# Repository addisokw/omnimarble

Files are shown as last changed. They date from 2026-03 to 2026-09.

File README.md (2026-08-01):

# OmniMarble -- Magnetic Coil Marble Coaster Digital Twin

A physics-accurate digital twin of a magnetic coil-launched marble roller coaster, built on NVIDIA's simulation stack (OpenUSD, PhysX, Kit SDK) with a Physics-Informed Neural Network (PINN) for real-time electromagnetic field computation.

## How It Works

A solenoid coil fires an RLC capacitor discharge through a coil to accelerate a ferromagnetic marble via electromagnetic force. The complete physics chain:

```
RLC Circuit (V, C, L, R)
    |
    v
Current I(t) -- underdamped oscillation with flyback diode
    |
    v
B-field (PINN: 6 inputs -> Br, Bz in single forward pass)
    |
    v
Gradient dB/dr, dB/dz (torch.autograd on PINN output)
    |
    v
Force F = (chi*V/mu0) * (B . nabla)B  -- with saturation + eddy braking
    |
    v
PhysX apply_force_at_pos() -- marble accelerates in Omniverse
```

### The PINN

The analytical Biot-Savart computation (30 loop iterations x scipy elliptic integrals) is replaced by a Physics-Informed Neural Network for real-time inference:

- **Architecture (v8, "physics by construction")**: NVIDIA PhysicsNeMo FullyConnected, 6x256 hidden, SiLU, skip connections. The network outputs a single scalar f; the vector potential is A_phi = r*f and the field is derived inside forward() via autograd: B_r = -r*df/dz, B_z = 2f + r*df/dr. This makes div(B)=0, curl consistency, and the on-axis boundary conditions **exact identities of the architecture**, not trained approximations.
- **Inputs**: (r, z, I, N, R_mean, L) -- spatial position + coil design parameters
- **Outputs**: (A_phi, B_r, B_z) -- same column contract as earlier direct-B models; the shared loader (`scripts/pinn_loader.py`) handles both generations via the checkpoint's `derived_b` flag
- **Key feature**: Model learns B/I (T/A), collapsing dynamic range across the full current range [0.5, 4000] A
- **Training**: 1.42M samples from analytical Biot-Savart (711 configs incl. failure-mined families), losses: data + far-field decay + z-mirror symmetry
- **Validation**: 5-level test suite -- field accuracy, gradient accuracy, force accuracy, design space coverage, physics consistency
- **Force**: needs field gradients, which are second derivatives of f (double backward through the forward-pass graph)

### RLC Circuit

The coil is driven by a capacitor discharge (underdamped RLC):

```
I(t) = (V0 / omega_d * L) * exp(-alpha * t) * sin(omega_d * t)
```

With coupled electromechanical ODE (back-EMF from marble motion), RK4 sub-stepping at 10us resolution, and flyback diode clamping.

Default circuit: 470uF capacitor, 50V charge, L=12.4uH, R_dc=0.080 ohm (config `resistance_ohm`) + 0.01 ESR + 0.02 wiring = R_total~=0.110 ohm -> underdamped (zeta=0.34). Peak current: 327A undamped amplitude V/(omega_d*L); ~198A true damped peak (the two pipelines historically reported different definitions -- see tests/test_coil_physics.py).

### Force Model

Force on a ferromagnetic sphere in a non-uniform field:

```
F = (chi_eff * V / mu0) * (B . nabla)B
```

Where:
- chi_eff = 3.0 (demagnetization-corrected susceptibility for a sphere)
- V = marble volume (mm^3)
- mu0 = 4*pi*1e-4 T*mm/A (mm-scaled)
- B and gradients from PINN autograd

Additional physics:
- **Saturation**: When B_internal > B_sat (1.8T), switches to saturated magnetization model
- **Eddy current braking**: F_eddy proportional to dB/dt and marble conductivity
- **Wire heating**: I^2*R thermal model with copper temperature coefficient

### Units

All computations use mm-based units:
- Distance: mm
- Current: A
- Field: T (Tesla)
- Force: mN (milliNewtons) -- because `[chi * mm^3 / (T*mm/A)] * T * T/mm = A*T*mm = mN`
- Mass: kg (PhysX requirement)
- mu0 = 4*pi*1e-4 T*mm/A

## Quick Start

### Prerequisites

- Python 3.12 or 3.13 — **not 3.14**, which has no `usd-core` wheels. If your
  system Python is newer, pin the project with `uv python pin 3.13` (uv
  downloads a managed interpreter; `.python-version` is gitignored).
- [uv](https://docs.astral.sh/uv/) package manager
- NVIDIA GPU (CUDA) for PINN training and inference
- [NVIDIA Kit SDK](https://github.com/NVIDIA-Omniverse/kit-app-template) for the Omniverse app

### 1. Install Dependencies

```bash
uv sync
```

This installs torch (CUDA 12.8), nvidia-physicsnemo, scipy, matplotlib, numpy, and other dependencies from `pyproject.toml`.

Verify the GPU is actually usable — a Blackwell card (RTX 50-series) needs
`sm_120` in torch's arch list, which the pinned cu128 build provides:

```bash
uv run python -c "import torch; print(torch.__version__, torch.cuda.get_arch_list())"
```

### 2. Train the PINN (or use existing checkpoint)

A trained checkpoint is included at `models/pinn_checkpoint/pinn_best.pt`
(v8 step-250k, `derived_b=True`). To retrain:

```bash
# Generate training data from analytical Biot-Savart (~1.42M samples)
uv run python scripts/generate_training_data.py

# Train v8 PINN (300k steps, ~4.7h on RTX 5090 — the data loss backprops
# through an autograd derivative, so every step is a double backward)
uv run python scripts/train_pinn.py
# Smoke test without touching the production checkpoint:
uv run python scripts/train_pinn.py --steps 500 --batch-size 16384 --out-name pinn_smoke
```

For remote GPU training (e.g., a more powerful machine on your network):
```bash
# Edit REMOTE_HOST and REMOTE_USER in the script, then:
bash scripts/remote_train.sh
# Pulls the result as pinn_v8_candidate.pt + step checkpoints to
# candidates/v8/ — promotion to pinn_best.pt is a manual decision after
# the adoption-gate evaluation (see below).
```

### 3. Validate the PINN

```bash
uv run python scripts/evaluate_pinn.py            # validates pinn_best.pt
uv run python scripts/evaluate_pinn.py --ckpt <path>   # validate a candidate
```

Runs a 5-level validation suite:
1. **Field accuracy**: Bz error vs analytical at 6 currents (12,800 points each)
2. **Gradient accuracy**: dB/dr, dB/dz via autograd vs finite-difference
3. **Force accuracy**: End-to-end F_z comparison at r=0 and r=5mm
4. **Design space**: 64 coil geometries (N x R_mean x L grid)
5. **Physics consistency**: div(B)=0, axial symmetry, z-mirror symmetry

Outputs:
- Console: PASS/FAIL per check
- Plots: `results/plots/pinn_validation/` (5 figures)
- JSON: `results/pinn_validation_report.json`
- Audit: `results/pinn_audit_report.md`

### 4. Analytical B-Field Validation

```bash
uv run python scripts/analytical_bfield.py
```

Generates reference plots in `results/plots/`.

### 5. Coil Design Optimizer

#### Web UI (Gradio)

```bash
uv run python scripts/coil_optimizer_app.py
```

Opens a browser UI for interactive multi-objective coil design optimization.
Features: constraint sliders, target-boost mode, Pareto plot, coupled ODE reranking.

#### CLI

```bash
uv run python scripts/optimize_coil_design.py
```

Headless optimization — prints top designs to console with Pareto plot saved to `results/`.

### 6. Run in NVIDIA Kit (Omniverse)

#### First-time setup

The Kit SDK is not vendored. `omnimarble.kit.bat` expects a
`kit-app-template` checkout **as a sibling of this repo**, with our app and
extension registered inside it. None of that wiring is tracked in git, so it
has to be redone on each new machine.

Verified against kit-app-template **110.2.0**. Windows needs no Visual Studio
— that template disables the C++ build step on `windows-x86_64`.

```cmd
REM 1. Clone kit-app-template next to this project
git clone https://github.com/NVIDIA-Omniverse/kit-app-template.git ..\kit-app-template

REM 2. A fresh clone has no source/ tree at all -- create it.
mkdir ..\kit-app-template\source\apps
mkdir ..\kit-app-template\source\extensions

REM 3. Register the app. Template 110.x expects a FLAT .kit file in
REM    source/apps -- not the nested apps/<name>/<name>.kit of older releases.
copy source\apps\omnimarble\omnimarble.kit ..\kit-app-template\source\apps\

REM 4. Link the extension back here so it stays live-editable. Path.resolve()
REM    follows the junction, so the extension's config/coil_params.json
REM    ancestor-walk still finds this project root.
mklink /J ..\kit-app-template\source\extensions\omni.marble.coaster ^
          source\extensions\omni.marble.coaster
```

Then register the app in the two build files in `../kit-app-template`.
Extensions are auto-discovered from the directory layout, so only the app
needs declaring:

```lua
-- premake5.lua -- append after the "Apps:" comment at the end
define_app("omnimarble.kit")
```

```toml
# repo.toml -- the section already exists with an empty list; fill it in
[repo_precache_exts]
apps = [
    "${root}/source/apps/omnimarble.kit",
]
```

Finally build (downloads ~10GB, one-time):

```cmd
cd ..\kit-app-template
.\repo.bat build
cd ..\omnimarble
```

#### Launch

```cmd
omnimarble.kit.bat
```

This launches Kit with the extension loaded directly from `source/extensions/` (live editing).

**First launch is slow.** The extension pip-installs its own torch into Kit's
embedded Python (3.12) at
`%LOCALAPPDATA%\ov\data\Kit\omnimarble\1.0\pip3-envs\default-3.12` — a
separate environment from this project's `.venv`. Both `torch` and
`torchvision` are pinned to `+cu128` builds in `extension.py`
(`TORCH_CUDA_VERSION` / `TORCHVISION_CUDA_VERSION`); without the pins pip
prefers PyPI's CPU-only Windows wheel and the PINN runs ~13x slower with no
other symptom. A healthy startup logs:

```
[PINN] torch 2.10.0+cu128 (CUDA 12.8), physicsnemo ready
[PINN] Loaded on cuda, checkpoint: ...\pinn_best.pt
```

If it says `CUDA None` or `Loaded on cpu`, a stale wheel is cached:
`omni.kit.pipapi.install` skips whenever the module already imports, so
delete `torch*` from that `pip3-envs` directory and relaunch. Note that
`torchvision` must go back too — `physicsnemo` imports `timm`, which imports
`torchvision`, and its absence surfaces misleadingly as *"Checkpoint was
trained with physicsnemo backend but nvidia-physicsnemo is not installed"*.

#### In the Kit app

1. Click **Load Scene** to open the USD marble coaster scene
2. Click **Configure PhysX** to set CCD, 500Hz timestep, damping
3. Click **Start Simulation** -- marble rolls down the track, triggers IR gates, fires the coil
4. Watch the console log for real-time telemetry (current, field, force, velocity)
5. Adjust **Charge Voltage** and **Capacitance** in the UI panel, click **Update Parameters**
6. Click **Stop Simulation** -- the run's trajectory is written to
   `results/trajectories/kit_launch_<V>V_<C>uF_<timestamp>.csv`

#### Scripted autorun (reproducible launch runs)

The full sequence (load scene, configure PhysX, voltage override, start,
stop after the exit gates fire, write CSV, quit) can be driven without
clicking:

```cmd
omnimarble.kit.bat --/exts/omni.marble.coaster/autorun=true --/exts/omni.marble.coaster/autorunVoltage=300
```

Optional: `autorunMaxSimSeconds` (default 12), `autorunKeepOpen=true` to
leave the app running after the CSV is written.

#### Trajectory export

Every physics step records time, position (world + coil-local z_along/r),
velocities, coil current, capacitor voltage, PINN force and Bz, wire
temperature, and trigger/cutoff flags. The CSV starts with `# key=value`
metadata lines (run parameters, PINN checkpoint + step, gate times,
approach/exit velocity, boost ratio).

A committed reference artifact from the real Kit/PhysX/PINN path:
`results/trajectories/kit_launch_300V_470uF_20260702_174018.csv` — 300V run,
approach 208 mm/s, gate-measured exit 937.5 mm/s (**4.5x boost**).

Use it to check a fresh machine: rerun the autorun command above and diff.
The gate-measured numbers and the `current_A` / `V_cap_V` / `Bz_T` /
`wire_temp_C` columns should match exactly. Positions and velocities drift
slightly (sub-0.1mm, well under 1% on velocity) — that is PhysX solver
nondeterminism across machines, not a broken setup.

#### What happens during simulation

1. Marble rolls down the starter slope under gravity
2. Two velocity-measurement IR gates compute approach velocity
3. Entry gate triggers the RLC discharge
4. Coupled electromechanical ODE computes current with 10us sub-stepping
5. PINN computes B-field, autograd computes gradients, force is applied via PhysX
6. Cutoff gate (MOSFET switch) kills the pulse when marble passes coil center
7. Two exit gates measure the launch velocity and compute boost ratio

## Project Structure

```
config/
  coil_params.json              # Source of truth: coil geometry + RLC circuit params

scripts/
  analytical_bfield.py          # Biot-Savart B-field (elliptic integrals) -- ground truth
  generate_training_data.py     # PINN training data from analytical solution (1.42M samples)
  pinn_loader.py                # Shared checkpoint loader + inference (legacy & derived-B)
  train_pinn.py                 # v8 derived-B PINN training (PhysicsNeMo)
  evaluate_pinn.py              # 5-level PINN validation suite (--ckpt for candidates)
  evaluate_candidates.py        # Multi-checkpoint Pareto comparison
  v7_optimization_diagnostic.py # PINN ranking stability diagnostic (--ckpt)
  physical_accuracy_audit.py    # Physics consistency validation
  validate_physics.py           # Physics validation utilities
  validate_kit_simulation.py    # Headless mirror of Kit physics (--field pinn|analytical)
  coil_optimizer_core.py        # Shared optimization engine (screening + coupled reranking)
  coil_optimizer_app.py         # Gradio web UI for coil design optimizer
  optimize_coil_design.py       # CLI coil design optimizer
  warp_bfield_solver.py         # PINN-based solver for headless simulation
  rlc_circuit.py                # RLC circuit utilities (saturation, eddy braking)
  remote_train.sh               # Remote GPU training via SSH
  generate_coil.py              # Parametric coil mesh generation
  em_force_injection.py         # Standalone EM force simulation
  simulation_loop.py            # Full orchestration loop
  optimize_launch.py            # Differentiable parameter optimization
  create_marble.py              # Marble actor creation
  compose_scene.py              # Scene composition from USD layers
  convert_stl_to_usd.py         # STL → USD conversion
  add_visuals.py                # Visual enhancement
  setup_launch_scene.py         # Launch scene setup
  run_physics_test.py           # Physics test runner

source/                         # NVIDIA Kit extension
  apps/omnimarble/
    omnimarble.kit              # Kit app configuration
  extensions/omni.marble.coaster/
    config/extension.toml       # Extension settings (overridable defaults)
    omni/marble/coaster/
      extension.py              # Main extension: RLC + PINN + PhysX force + UI + autorun
      coil_physics.py           # Pure-Python coil/RLC physics (unit-testable, no Kit deps)

tests/                          # pytest suite (uv run pytest)
  test_coil_physics.py          # Derived values vs config, RLC, gates, cross-checks
  test_rlc_circuit.py           # Saturation/eddy/thermal helpers, mm/mN/T unit system
  test_pinn_loader.py           # Loader version detection, derived-B structural guarantees

models/
  pinn_checkpoint/
    pinn_best.pt                # Production checkpoint: v8 step-250k, derived_b=True
                                # (historical v3-v7 checkpoints live in git history;
                                #  candidates/ holds gitignored periodic checkpoints)

usd/                            # USD scene layers
  marble_coaster_scene.usda     # Composed scene (references all layers)
  marble_actor.usda             # Marble rigid body (mass=0.00408kg)
  coil_geometry.usda            # Coil mesh
  coil_properties.usda          # Coil electrical properties
  track_geometry.usda           # Track collision mesh
  marble_trajectory.usda        # Trajectory reference
  physics_config.usda           # PhysX configuration
  visual_config.usda            # Visual settings

results/
  pinn_validation_report.json   # Validation metrics (machine-readable)
  pinn_audit_report.md          # Full PINN audit trail
  plots/                        # Generated validation plots

omnimarble.kit.bat              # Launch Kit from project root
```

## Configuration

All physical parameters live in `config/coil_params.json`:

```json
{
  "inner_radius_mm": 12.0,
  "outer_radius_mm": 18.0,
  "length_mm": 30.0,
  "num_turns": 30,
  "capacitance_uF": 470.0,
  "charge_voltage_V": 50.0,
  "esr_ohm": 0.01,
  "wiring_resistance_ohm": 0.02,
  "has_flyback_diode": true,
  "switch_type": "MOSFET"
}
```

The Kit extension reads this JSON as the primary source of truth. UI fields in Kit override individual values at runtime.

**Physical-build note:** the persisted `inductance_uH`/`resistance_ohm`
derive from a 12mm-former winding assumption, while the field model (and
the PINN trained on it) places the windings at R_mean = 15mm — no single
physical coil satisfies both. Build real coils to the field geometry and
overwrite these two values with LCR-measured ones; see
`hardware/README.md` ("Supported coils" / build sheet) for the full
analysis.

### Getting a stronger launch

The default 50V/470uF circuit stores only 0.59J — at 50V the EM force barely
changes the trajectory versus a plain gravity roll. For a visible launch:
- **300V / 470uF**: 21J stored — **demonstrated in Kit: 4.5x gate-measured
  boost** (artifact: `results/trajectories/kit_launch_300V_470uF_20260702_174018.csv`)
- To improve efficiency, increase coil inductance (more turns, tighter winding) so the discharge period (~5-20ms) matches the marble's transit time through the coil

## PINN Training Details

### Architecture (v8, physics by construction)
- NVIDIA PhysicsNeMo FullyConnected backbone
- 6 inputs: (r, z, I, N, R_mean, L); 1 raw output: scalar f
- A_phi = r*f; B_r = -r*df/dz and B_z = 2f + r*df/dr derived via autograd
  in forward() — div(B)=0, curl consistency, and on-axis BCs are exact
- 6 hidden layers x 256 units, SiLU activation, skip connections
- B/I normalization: model learns B/I (T/A), caller multiplies by I
- Canonical model + loader: `scripts/pinn_loader.py` (`BFieldPINNDerived`)

### Training data
- 1.42M samples from analytical Biot-Savart
- 75k spatial point pool: 30k dense near coil + 20k boundary-enriched + 5k on-axis + 20k far-field
- 711 parameter configs: grid corners + random + failure-mined N=10/R=8 families
- Per-config: 1500 general + 500 config-adaptive boundary points

### Loss function (v8)
- **Data loss**: MSE on derived B_r/I and B_z/I (backprops through the
  autograd derivative — the dominant per-step cost)
- **Far-field decay** (weight 0.1): fields -> 0 far from coil
- **z-mirror symmetry** (weight 0.5): Bz even, Br odd in z
- Progressive ramp: physics weights scale from 0.1x to 1.0x over first 20k steps
- Removed vs v7 (now exact by construction): curl, divergence-free, on-axis
  boundary conditions; gradient supervision dropped (third-order, marginal)
- Checkpoint selection by data loss + periodic saves for a post-hoc sweep

### Current validation status (v8 step-250k, production — 2026-07-02)

| Level | Check | Result |
|---|---|---|
| 1 | Field accuracy (mean/max Bz error) | FAIL max-only (mean 0.86%, max 27.8% at winding singularities; informational) |
| 2 | Gradient accuracy (dBz/dz mean + P99) | PASS (P99 3.05%) |
| 3 | Force accuracy (peak err, correlation, zero-crossing) | PASS (2.7% / 3.0%, r>0.994) |
| 4 | Design space (64 configs under 5%) | PASS (95.3%, worst 7.75%) |
| 5 | Physics consistency (div=0, symmetry) | PASS (div(B)=0 exact by construction) |

Optimizer-ranking diagnostic vs analytical reference: Spearman r=1.000,
Kendall tau=0.992 over 60 candidates — safe for design optimization.

See `results/pinn_audit_report.md` for the full audit trail including all
training iterations (v1-v8) and the adoption-gate decision.

## License

MIT

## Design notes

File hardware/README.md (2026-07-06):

# OmniMarble driver board (60V-class SELV coilgun pulse driver)

Experimental-side electronics for the OmniMarble digital twin: drives a
real coil with the same fire/cutoff logic as the simulation's Kit
extension and emits telemetry in the sim's trajectory-CSV format for
direct sim-to-real comparison.

> ⚠️ **vNext — on hold (2026-07-06).** This integrated driver board is not the
> current path. The launch concept is still unproven, so we stepped back to a
> bench rig built from off-the-shelf modules — see **[`V0_BENCH_RIG.md`](V0_BENCH_RIG.md)**.
> This board is DRC-clean and preserved; revisit once V0 proves the concept out.

**Status: layout final — fully routed, electrically DRC-clean (0 unconnected /
shorts / clearance / parity), all validators green, and the JLCPCB fab/assembly
package generated (`hardware/fab/jlc/`). Externally reviewed.**

- Operating point: bank charged **24.5–55 V** (63 V-rated capacitors,
  hardware OVP trips 59.1–62.0 V worst-case, asserted in
  `scripts/calcs.py`), one shot per several seconds.
- Bank: 5× snap-in positions, 2200 µF/63 V each (baseline 2 populated =
  4400 µF; max 11000 µF).
- Switch: 3× paralleled 150 V TOLL MOSFETs, designed to a **600 A / 2 ms**
  pulse point; MOSFET-cutoff + freewheel topology reproduces the sim's
  circuit model.
- All engineering numbers in `design-calcs.md` are generated and
  margin-asserted by `scripts/calcs.py` — do not hand-edit.

## Supported coils

The coil is off-board (J5 barrier terminals) and interchangeable. A coil
is **validated** iff it satisfies the envelope swept by `calcs.py` at the
worst configuration (11000 µF bank at 55 V):

> **L ≥ 1 µH AND R_total ≥ 90 mΩ** (total series resistance *including*
> leads and lugs — keep leads short and heavy)

Below the envelope the pulse can exceed the 600 A switch design point —
do not fire. The envelope numbers live in `coil-envelope.json` (generated
by calcs.py) and are printed on the flyback schematic sheet next to J5;
the full safe/unsafe sweep table is in `design-calcs.md`.

### Validated default: demo coil (the coil the simulation models)

| Parameter | Value |
|---|---|
| Turns / wire | 30 × 0.8 mm (AWG20), single layer |
| Geometry | inner r 12 mm, outer r 18 mm, length 30 mm |
| Inductance | 12.406 µH |
| R_dc / R_total | 80.2 mΩ / **110.2 mΩ** (incl. 30 mΩ ESR+wiring budget) |
| At 55 V / 11000 µF | ~420 A peak, ~1.1 ms, 16.6 J |

Using this coil keeps hardware runs directly comparable to Kit runs
(`config/coil_params.json` is the shared source of truth).

### KNOWN MODEL INCONSISTENCY (affects how you build the coil)

The simulation is internally inconsistent about where the windings sit:

- The **field model** (`analytical_bfield.solenoid_field`, which the PINN
  was trained on and the launch force derives from) places all 30 turns
  at a **single 15.0 mm radius** — the mean of config's inner 12 / outer
  18 mm.
- The **circuit model** (Wheeler inductance + winding resistance in
  `coil_physics.py` / `rlc_circuit.py`) assumes a single layer of 0.8 mm
  wire on a 12 mm former (wire centers ~12.4 mm), which is where config's
  persisted `inductance_uH = 12.406` and `resistance_ohm = 0.0802` come
  from.

No physical coil satisfies both. **Resolution: build to the FIELD
geometry** (that is what the PINN/force model is being validated
against), then reconcile the circuit side by measurement — the config
accepts measured `inductance_uH` / `resistance_ohm` and the RLC model
uses whatever is there. Building at 12 mm instead would bias the field
test: closer windings give a measurably stronger on-axis field than the
model predicts.

### Coil build sheet — experiment #1 (demo coil, field-geometry build)

The field model uses **ideal loop centers**: 30 loops at radius 15.0 mm
with centers at `np.linspace(-15, +15, 30)`. The physical winding must
match **turn centers**, not wire edges. Machine-readable spec:
`hardware/scripts/parts.py DEMO_COIL_BUILD`, contract-tested against the
field model by `tests/test_coil_physics.py::
test_demo_coil_build_matches_field_model` (fails if either side drifts).

| Item | Spec |
|---|---|
| Target geometry | **Wire CENTER radius = 15.0 mm** (this is the spec; former OD follows from your wire) |
| Former | For 0.87 mm finished wire OD (0.8 mm copper + 2×0.035 mm enamel): **~29.13 mm OD**. Measure your wire's finished OD and set former OD = 2×(15.0 − OD/2). 32 mm winding window between flanges |
| Wire | 0.8 mm copper (AWG20) enameled magnet wire, ~3 m incl. leads |
| Turns | **30 turns, single layer, one direction** |
| Spacing | **30 turn CENTERS evenly spanning 30.0 mm** → center-to-center pitch **30/29 ≈ 1.034 mm** (not 1.000). First and last turn centers sit at ±15.0 mm from coil center. NOT close-wound (that compresses the span to ~26 mm and shifts the field profile) |
| Leads | Short and heavy (>=AWG16 or doubled), crimped ring lugs to J5 |

Winding tips: score/print **1.034 mm-pitch** guide grooves (or a printed
thread) so the groove *centers* span exactly 30.0 mm; secure the ends
(CA glue) before the winding relaxes; leave 100 mm tails.

**Verify after winding** (LCR meter ~1 kHz + milliohm measurement), then
**write the measured values into `config/coil_params.json`** so sim and
hardware run identical circuit numbers:

| Quantity | Expected (field-geometry build) | Config's current value |
|---|---|---|
| Inductance | **~17.3 uH** (Wheeler at 15 mm) | 12.406 uH (12.4 mm assumption) |
| R_dc | **~97 mOhm** (2.83 m of AWG20) | 80.2 mOhm |
| R_total w/ leads | ~125–130 mOhm | 110.2 mOhm |
| Envelope check | 127 mOhm >= 90 mOhm, 17 uH >= 1 uH — inside; worst-case pulse ~430 A vs the 600 A design point | — |

### Experiment #2 (after #1 validates the model)

Wind the optimizer-recommended coil below; its predicted **+1.0 m/s
boost is itself a falsifiable prediction** of the digital twin.

### Optimizer-recommended coil for THIS board (55 V / 600 A constrained)

`uv run python scripts/optimize_coil_design.py --max-voltage 55 --max-current 600`
(PINN + coupled-ODE screening, 2000 LHS candidates, run 2026-07-03):

| Parameter | Value |
|---|---|
| Turns / wire | **75 × AWG18 (1.024 mm), 3 layers** |
| Geometry | inner r 8.5 mm, outer r 11.8 mm, length 30.5 mm |
| Inductance / R | 49.4 µH / R_dc 99 mΩ → R_total ~129 mΩ |
| Drive point | ~51 V, ~3700 µF (2 bank cans ≈ 4400 µF is the closest fit) |
| Pulse | 228 A peak, 1.6 ms, 4.8 J, ΔT ≈ 0.3 °C |
| Predicted boost | **+1.0 m/s (0.5 → 1.5 m/s, ~3×)** |

Envelope check: 129 mΩ ≥ 90 mΩ and 49.4 µH ≥ 1 µH — inside. Note the
earlier optimizer result quoted in the repo (396 V / 247 J design) was
computed for an unconstrained rig and is **not** a recommendation for
this board.

Caveat: these predictions come from the PINN + analytical circuit model.
Validating them against reality is this board's entire purpose — treat
the boost figure as a hypothesis, not a spec.

## Safety summary (details in design-calcs.md)

- Hardware interlock: FIRE = MCU_FIRE AND ARM-keyswitch (74LVC1G08), and
  the gate drivers are only powered through the E-STOP (NC) + keyswitch
  loop. Explicit pulldowns on all fire nets.
- Boost charging is fail-safe inhibited: a dead/absent Pico cannot charge.
- Hardware OVP (CJ431 ±0.5 %) independent of the MCU.
- Permanent 6.8 k bleed (3τ ≈ 224 s) + commanded 200 Ω dump (<5 V in
  5.3 s) + hardwired live-bank LED.
- Relays never break DC under load (sequencing: precharge before close,
  boost-inhibit before open, dump closes onto 0.28 A).

## Order/production gates

- `uv run python hardware/scripts/validate.py` — schematic completeness
  (review mode; warns on ORDER-REVIEW placeholders).
- `uv run python hardware/scripts/validate.py --production` — fab-export
  gate; **fails** while any ORDER-REVIEW placeholder remains. Currently
  clean: the R24 bank-bleed resistor is resolved to UNI-ROYAL
  25121WJ0682T4E / LCSC **C26073** (6.8 k, 1 W, 2512).
- BOMs: `bom/bom.csv` (engineering), `bom/bom_rail_emit.csv` /
  `bom_rail_recv.csv` (gate-rail variants incl. common parts). JLC
  assembly exports (`fab/jlc/bom_jlc.csv`, `cpl_jlc.csv`) are generated by
  `gen_fab.py`.

## Status & next phases

- **Done:** schematic; 4-layer 2 oz PCB layout (routed, electrically
  DRC-clean, datasheet-verified footprints for TOLL-8 / 9.5 mm barrier /
  5930 shunt / HF3FF relay); and the JLCPCB fab/assembly package
  (`hardware/fab/jlc/`, via `gen_fab.py`).
- **Next:** upload to JLC and clear its DFM (see `fab/jlc/ORDER_NOTES.md`);
  Pico firmware (fire/cutoff state machine, gate timestamps, DMA current
  capture, TRAJ_COLUMNS-compatible telemetry) + `compare_sim_real.py`;
  bring-up procedure — first power at 25 V floor, staged to 55 V, and
  **verify OVP trip + boost regulation before installing max bank
  capacitance or firing into the coil** (the 63 V-cap / 59.1–62.0 V OVP
  window is tight).

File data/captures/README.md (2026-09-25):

# Scope captures (Siglent SDS1202X-E via host/scope.py, omnimarble-vbench)

Columns: `t_s, i_A, v_bank_V`. Trigger on the bank edge (CH2 falling),
centred, 7 ms window, boxcar-averaged to ~2800 rows. `i_A` is the J6
shunt current (0.2 mV/A) -- the shunt is in the FET source leg and NEVER
sees the freewheel tail (TWIN_AUDIT S-9); integrals are shunt-visible only.

| file | date | bank | notes |
|---|---|---|---|
| scope_3can_10v_700.csv | 2026-08-29 | 9.65 V | blank |
| scope_3can_49v_{400,700,1500}.csv | 2026-08-29 | 49.15 V | blanks; tau=275 us tail fitted from these + marble dv |
| scope_3can_30v_700.csv | 2026-09-09 | 29.45 V | blank; 30 V injected prediction 69.6 -> measured 73.3 |
| scope_4can_49v_{400,700,1000,1500}.csv | 2026-09-24 | 49.8 V | blanks, 100 ohm charge resistor |
| scope_4can_22ohm_blank_49v_700.csv | 2026-09-24 | 49.77 V | blank after the 22 ohm swap (inert to the pulse) |
| scope_4can_marble_plus9_49v_700.csv | 2026-09-24 | 49.30 V | FIRST marble-shot capture, +9 offset; early slope -4.4% vs blank |
| scope_5can_49v_{400,700,1000,1500}.csv | 2026-09-24 | 49.8 V | blanks, 22 ohm resistor, PSU 1.0 A |
| scope_5can_marble_fwd_kick1_49v_1500.csv | 2026-09-25 | 49.73 V | marble, first forward kick of a sustain run at 0.85 m/s; early slope -2.7% -> ball at x ~ -17.2 mm |

Scoring and injected predictions: `docs/PREDICTION_45CAN.md`.

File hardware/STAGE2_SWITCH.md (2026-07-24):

# V0 Stage-2 Switch — low-side coil driver

The full-energy switch for the [V0 bench rig](V0_BENCH_RIG.md): a **low-side
N-MOSFET with a dedicated gate driver**. Low-side is the whole trick — the FET
source sits at ground, so the gate driver references ground and there's no
bootstrap / high-side complication.

Use this for Stage 1–2. A cheap prebuilt module can stand in for the Stage-0
electronics bring-up, but not the real experiment — see *Prebuilt board?* below.

## Schematic

```
                       V+  ● bank rail (24–45 V, held by C1)
                           │
          bench(+) ────────┤
          24–45 V,         ├───────────┬───────────────┬──────────────┐
          I-limited        │           │               │              │
                         ══╪══ C1     R_bleed         coil L1      (fire path)
                           │ 4700µF   1 kΩ 5 W        hand-wound        │
                           │ 63 V      │               │                │
                           │           │            ┌──┴──┐             │
                           │           │            │ P1  │ ACS758      │  optional
                           │           │            └──┬──┘ VIOUT→ADC   │  current sense
                           │           │               ● DRAIN          │
                           │           │        D1 ────┤                │
                           │           │       TVS     │   ┌────────────┴┐
                           │           │      5KP48A    ├─D─┤ Q1 IRFB4110 │
                           │           │     (D→S)      │   │  100 V FET  │
              Rg 10 Ω      │           │               │   │             │
   ┌──[///]── G ●──────────┼───────────┼───────────────┼─G─┤  gate       │
   │          │            │           │               │   │             │
   │       Rgs 10k         │           │            S ──┼─S─┤  source     │
   │          │            │           │               │   └─────────────┘
 ┌─┴────────┐ │            │           │               │
 │ U1 TC4420│ │            │           │               │
 │  OUT ────┘ │            │           │               │
 │  VDD ◄───── +12 V (gate-driver rail, small wall-wart)
 │  IN  ◄───── FIRE  (Pico GPIO, 3.3 V — TTL input, drives fine)
 │  GND ──┐   │            │           │               │
 └────────┘   │            │           │               │
    GND ●━━━━━┷━━━━━━━━━━━━┷━━━━━━━━━━━┷━━━━━━━━━━━━━━━━┷━━━━●  ★ STAR GROUND (bank −)
              (logic gnd and power gnd meet here — and ONLY here)
```

## Net list (unambiguous — build from this)

| Node | Everything on it |
|---|---|
| **V+** | bench supply (+), C1 (+), R_bleed (a), coil L1 (a) |
| **DRAIN** | coil L1 (b) → *via P1 ACS758* → Q1 **drain**, D1 TVS **cathode** |
| **GATE** | Q1 **gate**, Rg (b), Rgs (a) |
| **DRV_OUT** | U1 TC4420 OUT, Rg (a) |
| **SOURCE / GND_P** | Q1 **source**, Rgs (b), D1 TVS **anode**, C1 (−), R_bleed (b), bench supply (−) → ★star |
| **VDD12** | U1 VDD, C2/C3 (+), 12 V supply (+) |
| **FIRE** | U1 IN, Pico GPIO |
| **GND_L** | U1 GND, C2/C3 (−), 12 V supply (−), Pico GND → ★star |
| **ISENSE** | P1 ACS758 VIOUT → Pico ADC (P1 VCC→5 V, P1 GND→GND_L) |

## BOM

| Ref | Part | Why |
|---|---|---|
| Q1 | **IRFB4110** (100 V/180 A, TO-220, heatsinked) | pulse-rated FET; use IRFP4668 (200 V) if bank > 45 V |
| U1 | **TC4420CPA** gate driver (DIP-8, 6 A, non-inverting) | breadboardable; TTL input works off the 3.3 V Pico |
| Rg | 10 Ω ½ W | limits gate current / controls dV/dt |
| Rgs | 10 kΩ ¼ W | holds Q1 **off** if the driver is unpowered |
| D1 | **5KP48A** TVS (standoff 48 V, clamp ~77 V) | fast field collapse — see clamp note |
| C1 | 2200–4700 µF / 63 V | the energy bank |
| R_bleed | 1 kΩ 5 W across C1 | safety discharge (~5 s τ) |
| C2, C3 | 1 µF + 100 nF at U1 VDD | driver decoupling — keep leads short |
| P1 | ACS758LCB-100U (optional) | logs the pulse current to the Pico ADC |

## The three things that make or break it

1. **Clamp vs FET voltage.** D1 sits across drain-source; when Q1 opens, the coil
   dumps its current through the TVS, clamping V_DS to ~77 V (< the 100 V FET) and
   collapsing the field in **~150 µs** instead of the ~1 ms a plain freewheel diode
   gives. That fast collapse is the anti-suck-back. Rule: **standoff > bank voltage,
   clamp < 90 V**, so with the 100 V FET **keep the bank ≤ 45 V** and use the 5KP48A.
   Want more voltage → IRFP4668 (200 V) and the margin is huge.
   *A/B test:* swap D1 for an **MBR60100 freewheel** (anode→DRAIN, cathode→V+) and
   you'll see the slower collapse + more suck-back — confirms the clamp earns its place.
2. **Star ground.** The pulse loop (C1 → coil → Q1 → back to C1−) carries hundreds of
   amps. Logic ground (Pico, driver) touches it at **one point only** — the bank
   negative — or pulse noise walks straight into your sensor readings.
3. **Gate default-off.** Rgs guarantees Q1 is off before the driver powers up.

## Prebuilt board? Stage-0 only

Worth knowing after surveying the market: no off-the-shelf board gives you **both**
adequate voltage **and** high pulse current at our bank voltage, because the cheap
opto-isolated MOSFET switch modules are single-FET boards with a fixed volt-amp
product:

| Prebuilt variant | Fits our ≤45 V bank? | Pulse current? |
|---|---|---|
| 5–36 V modules (F5305S, ANMBEST) | ✗ under-volted | — |
| **100 V / 9.4 A** isolated switch | ✓ | ✗ current-starved (9.4 A) |
| 80 V / 18 A | ✓ | ✗ weak |
| 40 V / 50 A · 30 V / 161 A | ✗ under-volted | ✓ (but too low V) |

They're also opto-isolated at PWM speeds (~µs turn-off), which smears the precise
cutoff this whole rig depends on. **Verdict:**
- A **100 V / 9.4 A opto-isolated module** (3.3 V/5 V trigger) is a fine, *isolated,
  zero-build* switch for **Stage 0** — dry-firing the logic and confirming Pico
  timing + sensor reads at low energy without exposing the Pico.
- It is **too current-starved and too timing-smeared for Stage 1–2**. The discrete
  switch above is the only thing that delivers both the current headroom and the
  deterministic ~ns cutoff the timing experiment measures.

Also avoid the "IGBT driver boards" in this market — they're **inverter / welder
back-ends** (continuous SPWM controllers, high-voltage bus, no single-shot trigger),
not triggerable pulse switches, and an IGBT is the wrong device below ~250 V anyway
(VCE(sat) floor + turn-off tail current).

## Safe first-light sequence

1. **No bank connected.** Power 12 V + Pico → pulse FIRE → scope confirms GATE swings
   0 ↔ 12 V.
2. **Bank at ~10 V**, current limit ~0.5 A → fire a 200 µs pulse → scope DRAIN: pulls
   to ~0 on, clamps clean on turn-off.
3. **Add coil + ACS758**, repeat at 10 V, capture the current pulse.
4. **Ramp** per the [V0 Stage 0→1→2 protocol](V0_BENCH_RIG.md). Bleeder + shorting
   stick between voltage changes.

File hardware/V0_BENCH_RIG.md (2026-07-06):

# OmniMarble V0 Bench Rig — single-stage coilgun proof-of-concept

> **Current live hardware path (2026-07-06).** A breadboard-level rig wired from
> off-the-shelf modules to answer one question before we commit to a custom PCB.
> The integrated driver board and gate-rail sensor board are **vNext / on hold** —
> DRC-clean and preserved, to be revisited once V0 proves the concept out.
> See `fab/BOARD_OVERVIEW.md` and `fab/RAIL_OVERVIEW.md`.

## Why this exists

The integrated 55 V driver PCB is a lot of cost and time to commit for a concept
that is still **unproven**. Before spinning custom hardware, prove on the bench
that a **timed coil pulse boosts a steel marble the way the PINN predicts**.

The rig answers exactly one thing:

> **Does measured Δv = v_out − v_in match the sim across a voltage/timing sweep —
> and can we hit the firing timing to get it?**

Everything else is reused unchanged: the **Pico**, the **Waveshare sensor
modules**, and the **entire PINN / sim stack** (`scripts/`, `models/`,
`config/coil_params.json`). The only swap is *custom integrated driver* → *three
COTS modules and a hand-wound coil on the bench*, where every node is probeable.

## Architecture

Two paths — the high-current **power path** and the low-voltage **signal/control
path** — sharing only a star ground at the bank negative terminal.

```
 POWER PATH (high current, ≤60 V SELV)
 ┌──────────────┐   ┌───────────┐   ┌──────────────┐   ┌──────────────────────┐
 │ Bench supply │──▶│ Cap bank  │──▶│ N-MOSFET     │──▶│ Coil  (TVS/zener     │
 │ 24–48 V,     │   │ 2.2–4.7mF │   │ trigger      │   │ clamp across it)     │
 │ I-limited    │   │ 63 V      │   │ module       │   │  ▓▓▓ non-mag tube ▓▓▓ │
 └──────────────┘   │ +bleeder  │   └──────▲───────┘   │   ● steel marble →    │
                    └───────────┘          │ gate      └──────────────────────┘
                                           │
 SIGNAL / CONTROL PATH (logic, 3V3/5V)     │
 ┌────────────────┐                        │
 │ Waveshare A    │─5 lines─┐              │
 │ (BEFORE coil)  │         │        ┌─────┴──────┐
 └────────────────┘         ├──GPIO─▶│ Raspberry  │
 ┌────────────────┐         │        │ Pi Pico    │  reads v_in / v_out,
 │ Waveshare B    │─5 lines─┘        │            │  arms timed OFF, fires gate
 │ (AFTER coil)   │                  └────────────┘
 └────────────────┘
```

- **BEFORE** module → entry velocity `v_in` (marble crossing its 5 close sensors →
  Δt) **and** the coil-ON trigger.
- **AFTER** module → exit velocity `v_out`. `Δv = v_out − v_in` is the coil's boost.
- The Pico closes the loop; the FET module just switches; the supply/bank just
  store energy.

## Bill of materials

Spec-level with example parts — pick from what's on hand / in stock; nothing here
is a pinned SKU.

### Launcher (power path)

| Item | Spec | Example / note |
|---|---|---|
| Bench supply | Adjustable **24–48 V**, current-limited, ≥3 A | The current limit charges the bank gently and sets shot energy. A lab supply is ideal for iterating. |
| Cap bank | **2200–4700 µF, 63 V** electrolytic (one or a few) | ~3–6 J at 50 V — a real pulse, still manageable. Start at the low end. |
| Bleeder | **1–5 kΩ, ≥2 W** across the bank | Safety discharge — the bank holds charge. |
| Switch | **High-power N-MOSFET trigger module**, ≥60–100 V, tens of A peak, signal-in + power terminals | Or bare **IRFB4110** (100 V/180 A) + a gate-driver breakout (TC4420 / UCC27517). |
| Turn-off clamp | **TVS or zener** across the coil, clamp above bank V | Forces fast current decay = clean cutoff. **See suck-back note below.** |
| Coil | Hand-wound **18–22 AWG** enamelled magnet wire on a **non-magnetic** tube | Turns/length per the sim (`config/coil_params.json`). Or repurpose a solenoid. |
| Barrel + projectile | Non-magnetic tube (brass/aluminium/plastic) + **steel marble** | The tube is both barrel and sensor mount. |

**Clamp vs freewheel diode (important):** a plain freewheel diode across the coil
lets current keep circulating after the FET opens — slow decay, the field lingers,
and the marble gets *pulled back* (suck-back). A **TVS/zener clamp** at a higher
voltage forces the current down fast, which is what clean OFF timing needs. Your
existing **MBR60100** works as a starting freewheel, but plan to A/B it against a
TVS clamp.

### Sensing + control (signal path)

| Item | Spec | Example / note |
|---|---|---|
| Sensors | **2× Waveshare ITR20001/T** 5-ch reflective tracker module | Onboard LM393 comparators → **digital** outputs. One before, one after the coil. |
| Controller | **Raspberry Pi Pico** (or Pico W) | Reads sensors, computes firing, drives the FET gate. |
| Interconnect | 10 signal lines (5 + 5) + 5 V + GND | Pico has ~26 GPIO — plenty. |

## Wiring

- **Waveshare:** `VCC → +5 V`, `GND → common GND`. Its 5 digital outputs (per
  board) → **10 Pico GPIO** total. Because the modules threshold on-board, they go
  **straight to GPIO** — no external comparator needed.
- **FET module:** signal input ← a Pico GPIO (the fire line); module GND → common
  GND. Coil in series with the FET; bank across the FET + coil; **clamp across the
  coil**.
- **Grounding:** the pulse loop (bank → FET → coil) dumps tens of amps. Keep that
  loop physically short and tie logic ground to it at a **single star point (bank
  negative)** so pulse noise isn't injected into the sensor logic.

## Control / firing

- **ON:** the BEFORE module detects the marble approaching → Pico fires the coil ON.
- **OFF (the interesting part):** no sensor can sit at the coil *center* (the coil's
  there), so the cutoff is **open-loop from `v_in`**: feed `v_in` to the PINN, which
  predicts the **accelerated** transit-to-center — *not* `distance / v_in`, because
  the marble speeds up under the pulse — and the Pico arms the OFF timer accordingly.
  This is the digital twin closing its own loop.
- **Timing budget:** place the BEFORE module so there are a few ms between measuring
  `v_in` and the marble reaching the coil — enough for the Pico to compute and arm
  OFF. Don't butt it against the coil.

## Staged test protocol

Run in order — each stage de-risks the next.

1. **Stage 0 — dry fire (no marble).** Charge the bank low, fire the FET from the
   Pico, and scope the coil current pulse (current probe or a low-value sense
   resistor). Confirm: the FET switches, the clamp behaves, the Pico timing is what
   you commanded, and **both** Waveshare modules read cleanly. *Goal: the
   electronics + timing work before any marble is involved.*
2. **Stage 1 — first boost (marble, low energy).** Insert the marble, low bank
   voltage. Measure `v_in`, `v_out`. Confirm a **measurable Δv > 0** and that OFF
   fires before center (no suck-back deceleration). *Goal: the launcher does
   something, measurably.*
3. **Stage 2 — sim fit (ramp).** Sweep bank voltage and ON/OFF timing; log `v_in`,
   `v_out`, pulse current, and timing each shot. Fit measured **Δv vs the PINN
   prediction** across the sweep. *Goal: does the sim track reality? If yes, the
   integrated driver is a justified investment.*

## Safety

- Stay **≤60 V (SELV)**; charge through the supply's current limit.
- **Bleeder across the bank** — it holds charge. Bleeder + a shorting-stick habit
  before touching anything.
- **Clamp/diode on the coil** — inductive kick on turn-off.
- Keep the pulse loop short; fuse it if you scale energy.
- One shot per several seconds (thermal).

## Relationship to the rest of the project

- **Sim / PINN:** unchanged. The rig emits the same `v_in` / `v_out` observables the
  twin is validated against (`scripts/`, `models/`, `config/coil_params.json`).
- **vNext (on hold, preserved):** the integrated driver PCB
  (`fab/BOARD_OVERVIEW.md`) and gate-rail sensor board (`fab/RAIL_OVERVIEW.md`) —
  both DRC-clean. Revisit once V0 proves the concept.

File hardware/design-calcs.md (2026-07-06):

# Driver board design calculations

GENERATED by hardware/scripts/calcs.py — do not edit numbers by hand.

Coil model: L=12.406uH, R_total=0.1102Ohm (same values the simulation uses).

## Pulse envelope by bank option (at 55V)

| Bank | regime | zeta | I_pk | t_pk | pulse | E | I2t | FET dTj (shared/fault) | pour dT |
|---|---|---|---|---|---|---|-----|---|---|
| 2200uF | underdamped | 0.73 | 327A | 182us | 0.76ms | 3.3J | 30.2 A^2s | 3.2K / 28K | 0.02K |
| 4400uF | overdamped | 1.04 | 372A | 231us | 1.13ms | 6.7J | 60.1 A^2s | 4.3K / 38K | 0.04K |
| 6600uF | overdamped | 1.27 | 395A | 263us | 1.13ms | 10.0J | 86.4 A^2s | 6.1K / 55K | 0.05K |
| 8800uF | overdamped | 1.47 | 410A | 287us | 1.13ms | 13.3J | 107.4 A^2s | 7.6K / 69K | 0.07K |
| 11000uF | overdamped | 1.64 | 420A | 306us | 1.13ms | 16.6J | 123.9 A^2s | 8.8K / 79K | 0.08K |

Baseline population: **4400uF** (2x 2200uF snap-in).

## Margin checks

| Check | Detail | Result |
|---|---|---|
| Worst-case peak within switch design point | I_pk 420A <= 600A design point | PASS |
| Per-FET pulsed current (shared) | 140A/device <= IDM 760A (3x SCILICON SFT040N150C3 (TOLL, 150V, C42395334)) | PASS |
| FET junction rise, shared conduction | dTj 8.8K < 50K | PASS |
| FET junction rise, single-device fault (baseline bank) | dTj 38.4K < 150K at 4400uF (extreme-bank fault case: 79K — info only, requires all FETs functional) | PASS |
| Blocking diode I2t margin | pulse I2t/pkg 31 A^2s, rating 1012 A^2s (>=10x) | PASS |
| Shunt pulse energy | 24.8 mJ per shot (peak 35W for 1.1ms), continuous rating 15.0W | PASS |
| Pulse pour adiabatic heating | dT 0.08K per shot (20mm 2oz x2, R=0.61 mOhm) | PASS |
| ADC full scale vs worst peak | FS 750A >= 1.25 x 420A (LSB 0.18A) | PASS |
| Charge time (largest bank) | 0.67s to 55V at 0.5A (11000uF) | PASS |
| Dump to <5V (largest bank) | 5.3s through 200 Ohm dump | PASS |
| Passive bleed 3-tau (largest bank) | 3tau = 224s through 7k bleed | PASS |
| V_bank divider inside ADC range at OVP | 3.06V at 63V bank (divider 100k/5.10k) | PASS |
| Boost commanded max (PWM=0, fail state) | 55.0V ~= operating ceiling 55V (RT/RB/RJ = 100k/10k/9.1k) | PASS |
| Boost commanded min below converter floor | 18.7V < 24.5V floor (full PWM = converter idles) | PASS |
| OVP trip floor above commanded max | trip_min 59.1V > 55.0V + 1V margin (nominal 60.5V) | PASS |
| OVP trip ceiling below capacitor rating | trip_max 62.0V < 63V rating - 1V | PASS |
| Dump relay closing current within DC contact class | 0.28A resistive at 55V (HF3FF ~10A/28VDC class; opens only after discharge) | PASS |
| Relay coil drive within MMBT3904 | 30mA coil vs 200mA transistor rating | PASS |
| Coil envelope rectangle exists | L >= 1uH AND R_total >= 90 mOhm (all grid points inside are safe) | PASS |
| Demo coil inside validated envelope | demo 12.406uH/110 mOhm vs envelope L>=1uH, R>=90 mOhm | PASS |

## Sense chain

- Shunt 0.2 mOhm x INA240 gain 20 = 4 mV/A
- ADC full scale 750A at 3.0V ref, LSB 0.18A (12-bit)
- V_bank divider 100k/5.10k -> 2.67V at 55V, standing drain 0.52 mA

## Charger / discharge

- Boost floor 24.5V (cannot regulate below 24V input) — usable charge range 24.5-55V
- Charge current 0.5A avg; precharge 47 Ohm across the charge-relay contacts, relay closes only above 20V bank
- Permanent bleed 6.8k (0.44W at 55V); dump 200 Ohm (2x 100R/10W series) via relay

## Boost setpoint / OVP protection ladder

- VBOOST = 2.5 + RT*(2.5/RB - (VSET-2.5)/RJ) with RT/RB/RJ = 100k / 10k / 9.1k
- PWM=0 (fail state) -> 55.0V; PWM=100% -> 18.7V (< 24.5V floor, idle)
- Ladder: operating 55V < OVP 59.1..62.0V (TL431B +/-0.5% + 1% divider) < capacitor rating 63V
- Boost enable is fail-safe INHIBITED (pull-up holds COMP low; MCU must drive BOOST_EN_N low to charge)
- Relay sequencing: charge relay closes only after precharge equalization, opens only with boost inhibited; dump relay switches <=0.6A resistive.

## Coil safety envelope (worst case: full bank at operating ceiling)

A connected coil is validated iff **L >= 1 uH AND R_total >= 90 mOhm** (total series resistance including leads/wiring), swept at 11000uF / 55V against: I_pk <= 600A, FET dTj < 50K, diode I2t 10x, pour dT < 5K, ADC FS >= 1.25*I_pk.

| L \ R_total | 20m | 30m | 50m | 70m | 90m | 110m | 150m | 200m | 300m | 500m |
|---|---|---|---|---|---|---|---|---|---|---|
| 1uH | **2055A** | **1529A** | **1001A** | **741A** | OK | OK | OK | OK | OK | OK |
| 2uH | **1809A** | **1396A** | **949A** | **714A** | OK | OK | OK | OK | OK | OK |
| 3uH | **1653A** | **1305A** | **909A** | **694A** | OK | OK | OK | OK | OK | OK |
| 4uH | **1540A** | **1235A** | **877A** | **676A** | OK | OK | OK | OK | OK | OK |
| 5uH | **1452A** | **1180A** | **851A** | **661A** | OK | OK | OK | OK | OK | OK |
| 6uH | **1380A** | **1133A** | **827A** | **648A** | OK | OK | OK | OK | OK | OK |
| 8uH | **1268A** | **1058A** | **789A** | **625A** | OK | OK | OK | OK | OK | OK |
| 10uH | **1183A** | **999A** | **757A** | **606A** | OK | OK | OK | OK | OK | OK |
| 12.4uH | **1103A** | **942A** | **725A** | OK | OK | OK | OK | OK | OK | OK |
| 16uH | **1011A** | **876A** | **686A** | OK | OK | OK | OK | OK | OK | OK |
| 20uH | **935A** | **818A** | **651A** | OK | OK | OK | OK | OK | OK | OK |
| 30uH | **805A** | **718A** | OK | OK | OK | OK | OK | OK | OK | OK |
| 40uH | **720A** | **650A** | OK | OK | OK | OK | OK | OK | OK | OK |

(unsafe cells show the offending peak current; envelope excludes them by construction)

## Part constants used (verify against datasheets at order time)

- FET: SCILICON SFT040N150C3 (TOLL, 150V, C42395334), 3x parallel, Rds(on,hot) 6.0 mOhm, IDM 760A, Zth(1ms) 0.12 K/W
- Diode: YFW MBR60100DC (TO-263, 100V Schottky, C6069541), Vf 0.84V, IFSM 450A, I2t 1012 A^2s
- Shunt: Yezhan ASR-M-7-0.2F (5930, C469442, Kelvin-routed)

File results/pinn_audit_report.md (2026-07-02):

# PINN B-Field Model Audit Report

Last updated: 2026-07-02

## 1. Executive Summary

The Physics-Informed Neural Network (PINN) replaces the analytical Biot-Savart
B-field computation for a finite solenoid coilgun. It takes spatial position and
coil design parameters as input and produces the magnetic vector potential and
field components in a single forward pass.

**Current status: v8 "physics-by-construction" model (step-250k checkpoint)
deployed as the single production checkpoint `pinn_best.pt`. 4 of 5 levels
pass; Level 5 passes fully for the first time (div(B) = 0 exact by
architecture). The only remaining FAIL is the informational L1 max criterion
(27.8%, improved from v7's 37.2%; concentrated at winding singularities the
smooth network cannot represent). The v7-era dual-baseline strategy is
retired — see Section 12.**

| Check | v3 | v4 (field) | v5 (regressed) | v7 | **v8 (production)** |
|---|----|----|-----|---|---|
| Level 1: Field accuracy | FAIL | **PASS** | FAIL | FAIL (max only) | FAIL (max only, 27.8%) |
| Level 2: Gradient accuracy | FAIL | FAIL | FAIL | **PASS** (P99) | **PASS** (P99=3.05%) |
| Level 3: Force accuracy | FAIL | **PASS** | **PASS** | **PASS** | **PASS** (2.7%/3.0%) |
| Level 4: Design space | FAIL | FAIL (75%) | FAIL (61%) | **PASS (100%)** | **PASS (95.3%)** |
| Level 5: Physics consistency | FAIL (0/3) | FAIL (2/3) | FAIL (2/3) | FAIL (2/3, div=0.014) | **PASS (3/3, div=0 exact)** |

## 2. Problem Statement

The analytical Biot-Savart solenoid field computation requires 30 loop iterations
with scipy elliptic integrals per evaluation point. For real-time force computation
in Omniverse Kit at 500 Hz PhysX stepping, and for design exploration across coil
geometries, a faster surrogate model was needed.

## 3. Model Architecture

- **Backbone**: NVIDIA PhysicsNeMo FullyConnected
- **Hidden layers**: 6 x 256, SiLU activation, skip connections
- **Parameters**: ~331k
- **Inputs**: (r, z, I, N, R_mean, L) -- spatial position + coil design params
- **Outputs**: (A_phi, B_r, B_z)
- **Key feature**: Model learns B/I (T/A), collapsing dynamic range. Checkpoint flag `current_normalized=True`.

## 4. Training Data

### v3/v4 data (1.02M samples)
- **Spatial**: 30k dense + 20k boundary-enriched + 5k on-axis + 20k sparse = 75k pool
- **Configs**: 256 grid corners (N x R_mean x L at 4 currents) + 244 random + 11 default = 511
- **Points per config**: 1500 general + 500 boundary-enriched = 2000

### v5/v6 data (1.02M samples, same count)
- Same spatial pool and configs as v4
- **Added**: mid-grid parameter configs (N=20,40,65 x R=10,17 x L=22,38,52) for L4 coverage
- **Added**: analytical gradient targets (dBz/dz, dBz/dr) via vectorized finite differences
- **Added**: vectorized batch computation (~50x faster data generation)

## 5. Training History

### v1: Current range too narrow
- **Current range**: [0.5, 20] A
- **Result**: 97% error at operational currents (RLC peak ~320A)
- **Root cause**: Extrapolation failure -- model never saw currents above 20A

### v2: Double-normalization bug
- **Current range**: Fixed to [0.5, 4000] A
- **Result**: Still 97% error
- **Root cause**: `output_scale` double-normalization bug. Targets were divided by
  output_scale during preprocessing, then model output was multiplied by output_scale
  again in forward(), squaring the scaling.

### v3: B/I normalization fix (first passing model)
- **Key change**: Model learns B/I (T/A) not B(T). Collapses dynamic range.
- **Training**: 100k steps, batch_size=32768, lr=1e-3 cosine to 1e-6
- **Loss weights**: data=1.0, curl=0.1, div=0.1, BC=0.01
- **Best loss**: 8.28e-09
- **Hardware**: Local GPU
- **Validation result**: ALL 5 LEVELS FAILED (see Section 6.1)

### v4: Improved data + physics losses + symmetry (current best)
- **Data changes**: 1.02M samples, boundary enrichment, grid corners
- **Loss weight changes**: curl 0.1->1.0, div 0.1->1.0, BC 0.01->0.1
- **New losses**: Symmetry (z-mirror + on-axis Br=0, weight=0.5), gradient self-consistency (weight=0.1)
- **Progressive ramp**: Physics weights scale from 0.1x to 1.0x over first 20k steps
- **Training**: 200k steps, batch_size=131072, PDE batch=8192, BC/sym batch=4096
- **Best loss**: 1.70e-08
- **Hardware**: Remote RTX 5090 (32GB VRAM)
- **Validation result**: 3 of 5 levels pass (see Section 6.2)

### v5: Aggressive gradient supervision (REGRESSED)
- **Key change**: Direct gradient supervision from analytical dBz/dz, dBz/dr targets
- **Loss weights**: div 1.0->5.0, sym 0.5->2.0, grad 0.1->1.0 (against analytical targets)
- **Gradient loss**: Every 2nd step (was every 4th, self-consistency only)
- **Training**: 300k steps, batch_size=131072
- **Best loss**: 1.79e-07 (higher than v4 due to gradient loss dominating)
- **Hardware**: Remote RTX 5090
- **Validation result**: REGRESSED -- only 2/5 pass (see Section 6.3)
- **Root cause**: Gradient supervision weight (1.0) too high. Analytical gradient targets
  have extreme values near coil winding singularities (dBz/dr up to 877 T/mm/A). The model
  spent capacity fitting noisy gradient outliers at the expense of field accuracy. L1 mean
  error tripled (0.6% -> 1.6%), L4 coverage dropped (75% -> 61%), div(B) doubled.
- **Lesson**: Gradient supervision must be gentle (low weight + clipped targets) to act as
  a regularizer, not a primary loss.

### v6: Balanced gradient supervision (TRAINING)
- **Changes from v5**: grad weight 1.0->0.05, div 5.0->2.0, sym 2.0->1.0
- **Gradient targets**: Clipped to p0.5/p99.5 to remove singularity outliers
- **Gradient loss**: Every 4th step
- **Training**: 300k steps, batch_size=131072
- **Hardware**: Remote RTX 5090
- **Status**: Training in progress

## 6. Validation Results

### 6.1. v3 Checkpoint (baseline -- all failed)

Validation run: 2026-03-18, step=100000, loss=8.28e-09

#### Level 1: Field Accuracy -- FAIL
Grid: r in [0.1, 60] mm x z in [-80, 80] mm (12,800 points per current)

| Current | Bz mean err | Bz max err | Result |
|---|---|---|---|
| I=1A | 0.53% | 22.15% | FAIL |
| I=10A | 0.53% | 22.20% | FAIL |
| I=100A | 0.53% | 22.75% | FAIL |
| I=500A | 0.56% | 24.94% | FAIL |
| I=1000A | 0.59% | 27.03% | FAIL |
| I=3000A | 0.72% | 26.88% | FAIL |

#### Level 2: Gradient Accuracy -- FAIL

| Component | Mean err | P95 err | Max err |
|---|---|---|---|
| dBr_dr | 0.36% | 0.14% | 100.22% |
| dBr_dz | 0.44% | 0.28% | 99.65% |
| dBz_dr | 0.17% | 0.16% | 109.94% |
| dBz_dz | 0.63% | 0.28% | 100.35% |

#### Level 3: Force Accuracy -- FAIL

| Position | Peak F err | Pearson r | Zero-cross err | Result |
|---|---|---|---|---|
| r=0mm | 4.2% | 0.9987 | 39.78 mm | FAIL |
| r=5mm | 0.2% | 0.9988 | 0.45 mm | PASS |

#### Level 4: Design Space -- FAIL
- Configs with center Bz error < 5%: **62.5%** (need >= 95%)
- Worst center error: **29.55%** (need < 20%)

#### Level 5: Physics Consistency -- FAIL (0/3)

| Check | Value | Threshold | Result |
|---|---|---|---|
| div(B) = 0 | 0.037459 | < 0.01 | FAIL |
| Axial symmetry | 0.019203 | < 0.01 | FAIL |
| z-symmetry | 0.026788 | < 0.02 | FAIL |

---

### 6.2. v4 Checkpoint (current best -- 3/5 pass)

Validation run: 2026-03-18, step=200000, loss=3.04e-08

#### Level 1: Field Accuracy -- PASS

| Current | Bz mean err | Bz max err | Result |
|---|---|---|---|
| I=1A | 0.67% | 19.46% | PASS |
| I=10A | 0.67% | 19.46% | PASS |
| I=100A | 0.66% | 19.45% | PASS |
| I=500A | 0.61% | 19.40% | PASS |
| I=1000A | 0.57% | 19.31% | PASS |
| I=3000A | 0.58% | 18.79% | PASS |

#### Level 2: Gradient Accuracy -- FAIL

| Component | Mean err | P95 err | Max err |
|---|---|---|---|
| dBr_dr | 0.34% | 0.06% | 100.08% |
| dBr_dz | 0.42% | 0.11% | 99.87% |
| dBz_dr | 0.18% | 0.15% | 112.59% |
| dBz_dz | 0.62% | 0.18% | 99.84% |

#### Level 3: Force Accuracy -- PASS

| Position | Peak F err | Pearson r | Zero-cross err | Result |
|---|---|---|---|---|
| r=0mm | 1.9% | 0.9986 | 0.65 mm | PASS |
| r=5mm | 3.2% | 0.9970 | 0.22 mm | PASS |

#### Level 4: Design Space -- FAIL (improved)
- Configs with center Bz error < 5%: **75.0%** (need >= 95%, was 62.5%)
- Worst center error: **13.23%** (need < 20%, was 29.55% -- now passes worst-case)

#### Level 5: Physics Consistency -- FAIL (2/3 pass)

| Check | v3 value | v4 value | Threshold | Result |
|---|---|---|---|---|
| div(B) = 0 | 0.037459 | **0.019185** | < 0.01 | FAIL |
| Axial symmetry | 0.019203 | **0.002932** | < 0.01 | **PASS** |
| z-symmetry | 0.026788 | **0.012165** | < 0.02 | **PASS** |

---

### 6.3. v5 Checkpoint (regressed -- 2/5 pass)

Validation run: 2026-03-18, step=300000, loss=1.79e-07

**Root cause of regression**: Gradient supervision weight (1.0) too aggressive. Model
prioritized fitting noisy analytical gradient targets near singularities over field accuracy.

#### Level 1: Field Accuracy -- FAIL (regressed from v4 PASS)

| Current | Bz mean err | Bz max err | Result |
|---|---|---|---|
| I=1A | 1.62% | 30.62% | FAIL |
| I=10A | 1.62% | 30.59% | FAIL |
| I=100A | 1.64% | 30.39% | FAIL |
| I=500A | 1.75% | 34.01% | FAIL |
| I=1000A | 1.62% | 38.80% | FAIL |
| I=3000A | 2.15% | 32.63% | FAIL |

Mean errors tripled (0.6% -> 1.6%), max errors nearly doubled (19% -> 31-39%).

#### Level 2: Gradient Accuracy -- FAIL (similar to v4)

| Component | Mean err | P95 err | Max err |
|---|---|---|---|
| dBr_dr | 0.36% | 0.15% | 100.21% |
| dBr_dz | 0.45% | 0.33% | 99.42% |
| dBz_dr | 0.18% | 0.18% | 105.47% |
| dBz_dz | 0.65% | 0.30% | 99.56% |

Despite heavy gradient supervision, max errors unchanged (singularities are fundamental).

#### Level 3: Force Accuracy -- PASS

| Position | Peak F err | Pearson r | Zero-cross err | Result |
|---|---|---|---|---|
| r=0mm | 11.6% | 0.9975 | 0.19 mm | PASS |
| r=5mm | 9.4% | 0.9945 | 0.17 mm | PASS |

Peak errors higher than v4 (1.9/3.2% -> 11.6/9.4%) but still within threshold.

#### Level 4: Design Space -- FAIL (regressed)
- Configs with center Bz error < 5%: **60.9%** (was 75.0%)
- Worst center error: **32.87%** (was 13.23%)

#### Level 5: Physics Consistency -- FAIL (2/3 pass, div regressed)

| Check | v4 value | v5 value | Threshold | Result |
|---|---|---|---|---|
| div(B) = 0 | 0.019185 | **0.037530** | < 0.01 | FAIL |
| Axial symmetry | 0.002932 | **0.006640** | < 0.01 | PASS |
| z-symmetry | 0.012165 | **0.013792** | < 0.02 | PASS |

div(B) doubled despite 5x weight increase -- gradient loss competed with div loss.

## 7. Remaining Failure Analysis

### Level 2: Gradient max errors at singularities
The ~100% max gradient errors occur at isolated grid points near the coil winding surface
(r ~ R_mean = 15mm, z ~ +/-L/2 = +/-15mm). The analytical field has a near-discontinuity
from the current sheet model. A smooth PINN cannot reproduce this. P95 errors (< 0.3%)
confirm accuracy everywhere else. Level 3 (force) passing confirms these points don't
affect integrated quantities. The max threshold of 50% may be unreachable.

### Level 4: Design space corner coverage
~25% of the 64 grid configs still exceed 5% center error. These are configs where geometry
is extreme (e.g. N=80 in L=15mm = very tight winding, or N=10 in L=60mm = very sparse).

### Level 5: Divergence-free residual
div(B) = 0.019 (v4) vs 0.01 threshold. Concentrated near coil boundaries where spatial
gradients are steepest. v5 showed that increasing div weight alone doesn't help if it
competes with other losses.

## 8. Known Limitations

1. **Coil winding singularities**: Discrete current loop model creates near-singularities
   at (r=R_mean, z=loop_position). PINN cannot reproduce these.
2. **Extrapolation**: Accuracy degrades outside training bounds (N < 10 or > 80,
   R_mean < 6 or > 20 mm, L < 15 or > 60 mm, I > 4000 A).
3. **Gradient amplification**: Force uses autograd gradients -- field errors amplified.
4. **Linear B-I assumption**: B/I normalization breaks with ferromagnetic saturation.

## 9. Integration

- **Kit Extension**: `omni.marble.coaster` loads the PINN via `torch.load()` with
  `weights_only=False` (needed for PhysicsNeMo custom layers)
- **Dependencies**: torch and nvidia-physicsnemo installed via `omni.kit.pipapi`
  on first launch. Added `nvidia-physicsnemo` to `pyproject.toml` for standalone use.
- **Force path**: `PINNForceComputer` calls `model.forward()` with autograd enabled,
  computes (chi*V/mu0)(B.grad)B, applies via PhysX `apply_force_at_pos`
- **`current_normalized` flag**: Stored as a buffer in the checkpoint. When True,
  model outputs B/I -- all inference code multiplies by I before computing force
- **`warp_bfield_solver.py`**: Fixed to handle `current_normalized` buffer and I-scaling

### v7 ("design-space"): Audit-driven retraining (superseded by v8)
- **Key changes**: Active failure mining (N=10/R=8 families), gentle gradient supervision
  (weight 0.03, clipped targets), data-loss checkpoint selection, periodic saves
- **Data**: 1.42M samples (711 configs including failure-mined families)
- **Loss weights**: curl=1.0, div=1.5, BC=0.1, sym=0.5, grad=0.03
- **Training**: 300k steps, batch_size=131072
- **Best data loss**: 1.39e-08
- **Hardware**: Remote RTX 5090
- **Validation result**: L2+L3+L4 pass, L1 max and L5 div still fail (see Section 6.4)
- **Deployed as**: `pinn_designspace.pt` (2026-03; retired 2026-07 — was
  byte-identical to `pinn_best.pt`, which is now the single production name)

## 10. Checkpoint Comparison and Dual-Baseline Decision (v7 era, retired)

### Checkpoint sweep (v7 training run)

All periodic checkpoints were evaluated to determine whether an intermediate
checkpoint could achieve v7's L4 coverage while preserving lower L1 max error:

| Checkpoint | L1 mean | L1 P99 | L1 max | L4 %<5 | L4 worst | L3 pk err | L5 div |
|---|---|---|---|---|---|---|---|
| step 50k  | 1.25% | 11.02% | 71.0% | 64% | 15.4% | 7.1% | 0.024 |
| step 100k | 0.75% | 6.57% | 58.1% | 78% | 10.4% | 0.3% | 0.019 |
| step 150k | 0.78% | 4.41% | 42.7% | 92% | 5.4% | 4.9% | 0.016 |
| step 200k | 0.51% | 3.83% | 40.3% | 100% | 4.9% | 5.0% | 0.015 |
| step 250k | 0.58% | 3.49% | 38.0% | 98% | 5.4% | 6.1% | 0.014 |
| **final** | **0.50%** | **3.39%** | **37.2%** | **100%** | **4.8%** | **6.0%** | **0.014** |

**Conclusion**: L4 coverage and L1 max trade off monotonically. No intermediate
checkpoint achieves both v4-style L1 max (<20%) and v7-style L4 completeness (100%).
This is a real tradeoff in the learned solution, not a checkpoint-selection issue.

### Dual-baseline deployment decision (RETIRED 2026-07-02)

**Retirement note**: the strategy below never had a working second leg. The
original v4 checkpoint was lost during the v5-v7 iteration cycle, and the
recipe retrain produced L1 max = 47% — worse at pointwise field accuracy
than the design-space model it was meant to back up. `pinn_fieldaccuracy.pt`
and its training scripts were deleted (recoverable from git history), and
v8 (Section 12) improved L1 max to 27.8% anyway, weakening the case for a
separate field baseline. Preserved as written for the historical record:

Two named baselines are maintained:

**`pinn_designspace.pt`** (v7 final) -- primary production model
- Use for: Kit integration, force computation, design exploration
- Passes: L2 (P99=3.7%), L3 (force), L4 (100% design space)
- L1 max error (37%) concentrated in singular-boundary regions; does not prevent
  Level 3 force accuracy from passing
- L5 div(B) = 0.014, close to 0.01 threshold

**`pinn_fieldaccuracy.pt`** (v4, needs retraining) -- conservative field baseline
- Use for: applications requiring strict pointwise field accuracy near boundaries
- Would pass: L1 (max <20%), L3 (force)
- Known gap: L4 at 75% (design space incomplete)
- Note: original v4 checkpoint was overwritten during v5-v7 iteration cycle.
  Retraining with the v4 recipe is required to restore this baseline.

### Audit findings addressed

| Audit finding | Action taken | Result |
|---|---|---|
| Level 2 mis-specified (max at singularities) | Changed to P99 < 10% | **L2 now PASS** (P99=3.7%) |
| Level 4 under-covered by data | Active failure mining of N=10/R=8 families | **L4 100%** (was 75%) |
| Training loss not reliable for selection | Checkpoint selected by data loss, periodic saves | Better proxy + post-hoc sweep |
| Gradient supervision too aggressive (v5) | Weight 0.03 with clipped targets | No regression from v4 baseline |
| Process optimizing for wrong things | Dual-baseline framing, not single pass/fail | Honest tradeoff documented |

### Next experiment

The remaining L5 div(B) gap (0.014 vs 0.01) and the L1 boundary max error are both
candidates for a **physics-by-construction** approach: deriving B_r and B_z from A_phi
via autograd (B_r = -dA/dz, B_z = (1/r)d(rA)/dr) would guarantee div(B)=0 exactly.
This is the recommended next structural improvement, not further loss weight tuning.

**Done — implemented as v8, see Section 12.**

## 11. Training Infrastructure

- **Local machine**: Windows 11 (development, validation), RTX 5060 Ti
- **Remote training**: Windows SSH to RTX 5090 (32GB VRAM) at 10.10.1.187
  (ICMP firewalled — preflight with `ssh <host> "echo ok"`, not ping)
- **Workflow**: `scripts/remote_train.sh` or manual SCP + SSH
- **Data generation**: Vectorized batch computation (~50x faster than per-point loop)
- **v4 training time**: ~15min for 200k steps at batch_size=131072 on RTX 5090
- **v5 training time**: ~22min for 300k steps at batch_size=131072 on RTX 5090
- **v8 training time**: ~4.7h for 300k steps at batch_size=131072 on RTX 5090
  (the data loss backprops through an autograd derivative, so every step is a
  double backward — ~13x the v7 step cost)

## 12. v8: Physics by Construction (2026-07-02, production)

### Architecture change

The network head was reduced to a single scalar f(r, z, I, N, R_mean, L)
with the ansatz **A_phi = r · f**. The field is derived inside forward()
via autograd:

    B_r = -dA/dz         = -r · df/dz
    B_z = (1/r) d(rA)/dr = 2f + r · df/dr

Consequences, exact by architecture (not by training):
- div(B) = 0 (Level 5's div check is now structural)
- curl consistency B = curl(A)
- A_phi(0, z) = 0 and B_r(0, z) = 0 (the r·f parameterization removes the
  1/r axis singularity — no l'Hopital special case needed)

Losses removed as now-redundant: curl, div, on-axis boundary conditions,
and analytical gradient supervision (third-order through the derived field).
Remaining: data MSE on derived (Br/I, Bz/I), far-field decay (0.1),
z-mirror symmetry (0.5), progressive ramp. Checkpoint selection by data
loss with periodic saves, as in v7. Model/loader code:
`scripts/pinn_loader.py` (BFieldPINNDerived; the loader transparently
supports legacy and derived checkpoints via the `derived_b` flag).

Force gradients are now SECOND derivatives of f (double backward). The Kit
per-step cost was offset by merging the previous two PINN calls per physics
step (get_Bz + compute_force) into one graph build.

ONNX export was dropped (autograd inside forward is not traceable; nothing
consumed it).

### v8 training run

- **Data**: regenerated 1.42M samples / 711 configs (v7 failure-mining recipe)
- **Training**: 300k steps, batch 131072, RTX 5090, ~4.7h
- **Best data loss**: 1.57e-08 (at step 250k)

### Checkpoint sweep (v8)

| Checkpoint | L1 mean | L1 p99 | L1 max | L2 p99 | L3 pk / r | L4 %<5 | L4 worst | L5 div |
|---|---|---|---|---|---|---|---|---|
| step 50k  | 8.33% | 61.6% | 82.5% | 4.52% | 94.1% / 0.497 | 4.7% | 83.2% | 0.00000 |
| step 100k | 5.29% | 28.1% | 72.6% | 4.16% | 36.9% / 0.926 | 6.2% | 66.6% | 0.00000 |
| step 150k | 1.95% | 5.9% | 35.0% | 3.47% | 1.6% / 0.997 | 71.9% | 21.9% | 0.00000 |
| step 200k | 1.35% | 4.8% | 29.0% | 3.17% | 1.7% / 0.996 | 87.5% | 9.4% | 0.00000 |
| **step 250k** | **0.86%** | **2.8%** | **27.8%** | **3.05%** | **3.0% / 0.995** | **95.3%** | **7.75%** | **0.00000** |
| final 300k | 0.77% | 2.9% | 28.0% | 3.04% | 4.2% / 0.994 | 92.2% | 9.0% | 0.00000 |

div(B) is identically zero for every checkpoint — structural, as designed.
The v7 L1-max-vs-L4 tradeoff persists (final 300k has better L1 mean but
dips below the 95% L4 gate); **step 250k** is the only checkpoint passing
every gate criterion and was promoted.

### Adoption gate (all criteria met by step-250k)

| Criterion | Required | v8 step-250k | v7 (previous) |
|---|---|---|---|
| L3 force, both radii | peak<15%, r>0.95, zc<2mm | 2.7%/3.0%, 0.998/0.995, <0.4mm | 7.5%/6.0% |
| L4 design space | >=95% under 5%, worst<20% | 95.3%, 7.75% | 100%, 4.8% |
| L1 field | max <= 37.2% (no worse than v7), mean<5% | 27.8%, 0.86% | 37.2%, 0.50% |
| L5 physics | all pass | div=0 exact, axial+z-sym pass | div FAIL (0.0138) |
| Optimizer ranking | Spearman >= 0.99 | **1.000** (Kendall 0.992, max shift +/-1) | 0.9997 |

Promoted 2026-07-02: `models/pinn_checkpoint/pinn_best.pt` = v8 step-250k
(`model_version=8`, `derived_b=True`). v7 remains recoverable from git
history (commit 9a0c15d's parent).

### First Kit/PhysX launch artifact (300V)

Run via the extension's scripted autorun
(`--/exts/omni.marble.coaster/autorun=true --/exts/omni.marble.coaster/autorunVoltage=300`):

- Approach velocity 208 mm/s (vel_in gate pair); coil fired at entry gate
- 300V / 470uF = 21.1J stored, underdamped (zeta=0.339)
- MOSFET pulse cut at the cutoff gate
- **Gate-measured exit velocity 937.5 mm/s -> 4.5x boost** (README's
  predicted ~4.5x at 300V)
- Artifact: `results/trajectories/kit_launch_300V_470uF_20260702_174018.csv`
  (528 steps at 500 Hz, with metadata headers) — the first trajectory from
  the real Kit/PhysX/PINN path; all earlier committed trajectories came
  from the headless numpy integrators.
- Headless cross-check (`validate_kit_simulation.py --field pinn
  --voltage 300`): 4.2x boost — ratios agree within ~7%. Absolute
  velocities differ through the simpler sphere-bounce track collision
  (approach 149 vs 208 mm/s). Note the two pipelines report I_peak
  differently: the extension logs the undamped amplitude V/(omega_d*L)
  (1963A at 300V) while rlc_circuit reports the true damped peak (1187A);
  same circuit, different definitions (cross-checked in
  tests/test_coil_physics.py).

### Remaining known gaps

1. L1 max error (27.8%) at winding singularities — fundamental to the
   current-sheet analytical model vs a smooth network; informational.
2. All validation is against the analytical model; no physical-hardware
   validation exists yet (the sim-to-real loop of the original plan).
3. `coil_physics.py` (Kit) and `rlc_circuit.py` (headless) duplicate RLC
   physics — cross-checked by tests, unification is tracked tech debt.

---

### Validation run: 2026-03-18 22:38:41 (step=300000, loss=2.02e-08, 3/5 pass)

| Check | Result |
|---|---|
| Level 1: Field accuracy | FAIL |
| Level 2: Gradient accuracy | PASS |
| Level 3: Force accuracy | PASS |
| Level 4: Design space | PASS |
| Level 5: Physics consistency | FAIL |

**Level 1: Field Accuracy**

| Current | Bz mean err | Bz max err | Result |
|---|---|---|---|
| I=1A | 0.50% | 37.68% | FAIL |
| I=10A | 0.50% | 37.63% | FAIL |
| I=100A | 0.50% | 37.17% | FAIL |
| I=500A | 0.49% | 35.49% | FAIL |
| I=1000A | 0.49% | 34.26% | FAIL |
| I=3000A | 0.62% | 38.98% | FAIL |

**Level 2: Gradient Accuracy** (I=318A)

| Component | Mean err | P95 err | Max err |
|---|---|---|---|
| dBr_dr | 0.35% | 0.08% | 100.02% |
| dBr_dz | 0.43% | 0.16% | 99.85% |
| dBz_dr | 0.16% | 0.23% | 107.39% |
| dBz_dz | 0.62% | 0.22% | 100.01% |

**Level 3: Force Accuracy**

| Position | Peak F err | Pearson r | Zero-cross err | Result |
|---|---|---|---|---|
| r=0mm | 7.5% | 0.9941 | 0.68 mm | PASS |
| r=5mm | 6.0% | 0.9980 | 0.02 mm | PASS |

**Level 4: Design Space**
- Configs under 5%: 100.0% (need 95%)
- Worst: 4.80% (need <20%)

**Level 5: Physics Consistency**
- div_B: mean_normalized=0.013843 [FAIL]
- axial_symmetry: max_Br_over_Bz=0.003147 [PASS]
- z_symmetry: max_asymmetry=0.005018 [PASS]

---

### Validation run: 2026-03-19 10:43:05 (step=200000, loss=2.64e-08, 2/5 pass)

| Check | Result |
|---|---|
| Level 1: Field accuracy | FAIL |
| Level 2: Gradient accuracy | PASS |
| Level 3: Force accuracy | PASS |
| Level 4: Design space | FAIL |
| Level 5: Physics consistency | FAIL |

**Level 1: Field Accuracy**

| Current | Bz mean err | Bz max err | Result |
|---|---|---|---|
| I=1A | 0.60% | 47.01% | FAIL |
| I=10A | 0.59% | 47.00% | FAIL |
| I=100A | 0.59% | 46.91% | FAIL |
| I=500A | 0.60% | 46.52% | FAIL |
| I=1000A | 0.61% | 46.02% | FAIL |
| I=3000A | 0.70% | 44.19% | FAIL |

**Level 2: Gradient Accuracy** (I=318A)

| Component | Mean err | P95 err | Max err |
|---|---|---|---|
| dBr_dr | 0.35% | 0.08% | 100.03% |
| dBr_dz | 0.43% | 0.18% | 99.95% |
| dBz_dr | 0.16% | 0.27% | 106.22% |
| dBz_dz | 0.62% | 0.24% | 99.91% |

**Level 3: Force Accuracy**

| Position | Peak F err | Pearson r | Zero-cross err | Result |
|---|---|---|---|---|
| r=0mm | 0.0% | 0.9966 | 0.17 mm | PASS |
| r=5mm | 2.2% | 0.9977 | 0.03 mm | PASS |

**Level 4: Design Space**
- Configs under 5%: 90.6% (need 95%)
- Worst: 11.69% (need <20%)

**Level 5: Physics Consistency**
- div_B: mean_normalized=0.021017 [FAIL]
- axial_symmetry: max_Br_over_Bz=0.002915 [PASS]
- z_symmetry: max_asymmetry=0.007274 [PASS]

---

### Validation run: 2026-07-02 12:43:08 (step=300000, loss=2.02e-08, 3/5 pass)

| Check | Result |
|---|---|
| Level 1: Field accuracy | FAIL |
| Level 2: Gradient accuracy | PASS |
| Level 3: Force accuracy | PASS |
| Level 4: Design space | PASS |
| Level 5: Physics consistency | FAIL |

**Level 1: Field Accuracy**

| Current | Bz mean err | Bz max err | Result |
|---|---|---|---|
| I=1A | 0.50% | 37.68% | FAIL |
| I=10A | 0.50% | 37.63% | FAIL |
| I=100A | 0.50% | 37.17% | FAIL |
| I=500A | 0.49% | 35.49% | FAIL |
| I=1000A | 0.49% | 34.26% | FAIL |
| I=3000A | 0.62% | 38.98% | FAIL |

**Level 2: Gradient Accuracy** (I=318A)

| Component | Mean err | P95 err | Max err |
|---|---|---|---|
| dBr_dr | 0.35% | 0.08% | 100.02% |
| dBr_dz | 0.43% | 0.16% | 99.85% |
| dBz_dr | 0.16% | 0.23% | 107.39% |
| dBz_dz | 0.62% | 0.22% | 100.01% |

**Level 3: Force Accuracy**

| Position | Peak F err | Pearson r | Zero-cross err | Result |
|---|---|---|---|---|
| r=0mm | 7.5% | 0.9941 | 0.68 mm | PASS |
| r=5mm | 6.0% | 0.9980 | 0.02 mm | PASS |

**Level 4: Design Space**
- Configs under 5%: 100.0% (need 95%)
- Worst: 4.80% (need <20%)

**Level 5: Physics Consistency**
- div_B: mean_normalized=0.013843 [FAIL]
- axial_symmetry: max_Br_over_Bz=0.003147 [PASS]
- z_symmetry: max_asymmetry=0.005018 [PASS]

---

### Validation run: 2026-07-02 17:32:11 (step=300000, loss=2.80e-08, 3/5 pass)

| Check | Result |
|---|---|
| Level 1: Field accuracy | FAIL |
| Level 2: Gradient accuracy | PASS |
| Level 3: Force accuracy | PASS |
| Level 4: Design space | FAIL |
| Level 5: Physics consistency | PASS |

**Level 1: Field Accuracy**

| Current | Bz mean err | Bz max err | Result |
|---|---|---|---|
| I=1A | 0.82% | 28.30% | FAIL |
| I=10A | 0.82% | 28.28% | FAIL |
| I=100A | 0.77% | 28.04% | FAIL |
| I=500A | 0.61% | 26.90% | FAIL |
| I=1000A | 0.59% | 25.73% | FAIL |
| I=3000A | 1.24% | 29.25% | FAIL |

**Level 2: Gradient Accuracy** (I=318A)

| Component | Mean err | P95 err | Max err |
|---|---|---|---|
| dBr_dr | 0.34% | 0.05% | 100.02% |
| dBr_dz | 0.42% | 0.12% | 99.78% |
| dBz_dr | 0.16% | 0.15% | 109.26% |
| dBz_dz | 0.61% | 0.15% | 100.02% |

**Level 3: Force Accuracy**

| Position | Peak F err | Pearson r | Zero-cross err | Result |
|---|---|---|---|---|
| r=0mm | 0.7% | 0.9981 | 0.19 mm | PASS |
| r=5mm | 4.2% | 0.9943 | 0.33 mm | PASS |

**Level 4: Design Space**
- Configs under 5%: 92.2% (need 95%)
- Worst: 8.99% (need <20%)

**Level 5: Physics Consistency**
- div_B: mean_normalized=0.000000 [PASS]
- axial_symmetry: max_Br_over_Bz=0.002266 [PASS]
- z_symmetry: max_asymmetry=0.012700 [PASS]

---

### Validation run: 2026-07-02 17:33:29 (step=250000, loss=1.57e-08, 4/5 pass)

| Check | Result |
|---|---|
| Level 1: Field accuracy | FAIL |
| Level 2: Gradient accuracy | PASS |
| Level 3: Force accuracy | PASS |
| Level 4: Design space | PASS |
| Level 5: Physics consistency | PASS |

**Level 1: Field Accuracy**

| Current | Bz mean err | Bz max err | Result |
|---|---|---|---|
| I=1A | 0.92% | 28.04% | FAIL |
| I=10A | 0.91% | 28.03% | FAIL |
| I=100A | 0.86% | 27.85% | FAIL |
| I=500A | 0.70% | 26.83% | FAIL |
| I=1000A | 0.71% | 25.61% | FAIL |
| I=3000A | 1.46% | 29.67% | FAIL |

**Level 2: Gradient Accuracy** (I=318A)

| Component | Mean err | P95 err | Max err |
|---|---|---|---|
| dBr_dr | 0.34% | 0.05% | 100.01% |
| dBr_dz | 0.42% | 0.11% | 99.78% |
| dBz_dr | 0.16% | 0.15% | 109.16% |
| dBz_dz | 0.61% | 0.16% | 99.99% |

**Level 3: Force Accuracy**

| Position | Peak F err | Pearson r | Zero-cross err | Result |
|---|---|---|---|---|
| r=0mm | 2.7% | 0.9981 | 0.33 mm | PASS |
| r=5mm | 3.0% | 0.9945 | 0.39 mm | PASS |

**Level 4: Design Space**
- Configs under 5%: 95.3% (need 95%)
- Worst: 7.75% (need <20%)

**Level 5: Physics Consistency**
- div_B: mean_normalized=0.000000 [PASS]
- axial_symmetry: max_Br_over_Bz=0.002320 [PASS]
- z_symmetry: max_asymmetry=0.017698 [PASS]

---

### Validation run: 2026-07-02 17:47:03 (step=250000, loss=1.57e-08, 4/5 pass)

| Check | Result |
|---|---|
| Level 1: Field accuracy | FAIL |
| Level 2: Gradient accuracy | PASS |
| Level 3: Force accuracy | PASS |
| Level 4: Design space | PASS |
| Level 5: Physics consistency | PASS |

**Level 1: Field Accuracy**

| Current | Bz mean err | Bz max err | Result |
|---|---|---|---|
| I=1A | 0.92% | 28.04% | FAIL |
| I=10A | 0.91% | 28.03% | FAIL |
| I=100A | 0.86% | 27.85% | FAIL |
| I=500A | 0.70% | 26.83% | FAIL |
| I=1000A | 0.71% | 25.61% | FAIL |
| I=3000A | 1.46% | 29.67% | FAIL |

**Level 2: Gradient Accuracy** (I=318A)

| Component | Mean err | P95 err | Max err |
|---|---|---|---|
| dBr_dr | 0.34% | 0.05% | 100.01% |
| dBr_dz | 0.42% | 0.11% | 99.78% |
| dBz_dr | 0.16% | 0.15% | 109.16% |
| dBz_dz | 0.61% | 0.16% | 99.99% |

**Level 3: Force Accuracy**

| Position | Peak F err | Pearson r | Zero-cross err | Result |
|---|---|---|---|---|
| r=0mm | 2.7% | 0.9981 | 0.33 mm | PASS |
| r=5mm | 3.0% | 0.9945 | 0.39 mm | PASS |

**Level 4: Design Space**
- Configs under 5%: 95.3% (need 95%)
- Worst: 7.75% (need <20%)

**Level 5: Physics Consistency**
- div_B: mean_normalized=0.000000 [PASS]
- axial_symmetry: max_Br_over_Bz=0.002320 [PASS]
- z_symmetry: max_asymmetry=0.017698 [PASS]

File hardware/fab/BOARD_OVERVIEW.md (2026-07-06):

# OmniMarble Driver PCB — Board Overview (handoff)

> ⚠️ **vNext — on hold (2026-07-06).** The driver board is **not the current
> path**. The launch concept is still unproven, so the project stepped back to a
> bench rig built from off-the-shelf modules — see
> **[`../V0_BENCH_RIG.md`](../V0_BENCH_RIG.md)**. This board is DRC-clean and fully
> preserved; revisit once V0 proves the concept out. The handoff below remains the
> authoritative description of the board *as designed*.

> Authoritative handoff for the driver board *as designed*. Supersedes
> `REVIEW_HANDOFF.md` (which is from the earlier freerouting routing attempt and
> is out of date). Last updated 2026-07-05.

## What it is
A **coilgun-style pulse driver board** — the experimental-hardware side of the
OmniMarble project. It charges a capacitor bank to an elevated SELV voltage
(~55V), then dumps it through a coil via paralleled power MOSFETs, with
closed-loop current sensing and a safety interlock chain. Designed for JLCPCB
assembly; controlled by an external Raspberry Pi Pico (or compatible) via header.

**Repo:** `hardware/omnimarble-driver/omnimarble-driver.kicad_pcb` (KiCad 10 project)

## Key specs
| | |
|---|---|
| Board | 220 × 150 mm, 4-layer; **2oz outer / 1oz inner** copper; ENIG finish |
| Layer stack | F.Cu (signal) / In1 (GND plane) / In2 (GND plane) / B.Cu (signal) |
| Components | 177 footprints, 108 nets |
| Bank voltage | ≤55V SELV (functional isolation) |
| Status | **Fully routed, electrically DRC-clean** (0 unconnected / shorts / clearance / courtyard / parity / annular / hole). Remaining DRC = 16 cosmetic silk warnings. |

## Architecture / subsystems

**Power input & rails**
- 24V barrel jack (J1) → fuse (F1) → reverse-polarity protection (Q90 AOD4185 P-FET) → `+24V`
- Buck U1 (AP63205) → `+5V`; 12V linear U2 (78L12) → `+12V`; `3V3` for logic/ADC

**Boost charger** (charges the cap bank)
- U4 (UC3843B current-mode PWM) + Q91 (AOD66923 N-FET) + L2 → `VBOOST` → cap bank `VBANK`
- Bank sense divider → U3 (MCP6002) buffers `VBANK_SENSE` / `V24_SENSE`; OVP reference U5 (TL431BIDBZR)
  - **OVP authority caveat:** U5's cathode sits on the UC3843 COMP pin and can only clamp it to
    ~2–2.5 V — it *throttles* the boost but cannot reach zero duty (needs COMP < 1.4 V), so the
    analog OVP slows but does not fully stop a runaway in the divider-fault case. The **authoritative
    over-voltage cut is firmware** (`VBANK_SENSE > threshold → BOOST_EN_N`, driving Q1 which saturates
    COMP with full authority). Accepted for the first spin (see `ORDER_NOTES.md` bring-up item 2);
    rev-2 gives the TL431 full authority via a PNP off BST_VREF onto COMP/Q1.

**Cap bank & pulse stage** (the high-current path)
- 5 bulk caps (2 radial + 3 screw-terminal), `VBANK` pours
- Coil switch: **Q10/Q11/Q12 (SFT040N150C3, 150V) in parallel** — drains on `SW_DRAIN`, sources on `SHUNT_HI`
- Gate drivers U7/U8 (UCC27524A) → `QG1-3` / `DRV1-3`; snubbers `SNB1-3`
- Flyback clamp: MBR60100 diodes D9-D12 (`COIL_HI`); coil connects at J5

**Current sense** (Kelvin)
- Shunt RS1 (low-side, between `SHUNT_HI` and GND), tapped via net-ties NT1/NT2 → `ISNS_P` / `ISNS_N`
- U9 (INA240A1) current-sense amp → `IMON` → U10 (ADS7042 12-bit SAR ADC) → SPI to MCU

**Sensor front-end & logic**
- U11/U12 (LM339 quad comparators): IR-sensor thresholds — `CIN1-6`, `GATE1-6`, `SIG1-6`, `VTH_GATE`

**Safety interlock**
- E-stop (`ESTOP_SENSE` / `ESTOP_OK`), arm (`ARM_SENSE`), fire gating: `MCU_FIRE` AND'd through U6 (74LVC1G08) → `FIRE_GATED`
- Charge/dump relays K1/K2 (`RLY_CHARGE` / `RLY_DUMP`), dump resistors; buzzer BZ1 (Q4 driver)

**MCU interface**
- Pico sockets J9/J10; IDC connectors J6/J7/J8; aux/status LEDs

## How the board is generated (fully scripted, reproducible)
1. `hardware/scripts/gen_schematic.py` → schematic + netlist + `.kicad_pro` (DRC rules)
2. `hardware/scripts/placement.py` → placement, net widths/classes, critical-net taxonomy, authored-copper specs
3. `gen_pcb.py preroute` → places parts, pours planes, authors critical copper
   (Kelvin ties, U10 fine-pitch escape, SHUNT_HI B.Cu bus), exports Specctra DSN
4. `dsn_fixup.py` → net classes, name sanitizing, lock critical/pulse copper → DSN uploaded to
   **DeepPCB** (cloud router) for bulk signal routing (diff-pair mode OFF — see gotchas)
5. **`gen_pcb.py import-clean`** → imports routed SES + deterministic finishing
   (`author_shunt_hi_bus`, `deeppcb_repairs`, `local_finish`, `tidy_silk`,
   `fix_thin_annular`, F/B GND flood, `inject_stackup`, fill) → final board

**Regenerate the exact current board:** copy
`hardware/omnimarble-driver/omnimarble-driver-5-rev-39.ses` → `omnimarble-driver.ses`,
then `gen_pcb.py import-clean` (the frozen routed input — the corrected-netlist
DeepPCB re-route with the FET-strip keepout). This reproduces the DRC-clean board
from scratch; `deeppcb_repairs` re-applies the SHUNT_HI bus/Kelvin/pour fixups the
router couldn't be trusted to keep. Run with KiCad 10's bundled Python:
`"C:\Program Files\KiCad\10.0\bin\python.exe"`.

## Design decisions / gotchas (READ before editing)
- **Critical authored copper is locked and intentional** — a router must not touch it:
  the ISNS **Kelvin ties** (RS1→NT1/NT2); the **U10 dogbone escape** (fine-pitch ADS7042,
  0.2mm stubs to open-space vias); the **SHUNT_HI B.Cu bus** (ties the 3 FET sources to the
  shunt — the F.Cu pour fragments and can't be trusted for that current path).
- **ISNS_P/N are 0.15mm traces** (JLC 2oz min trace/space). A scoped rule in `.kicad_dru`
  (`isns_kelvin_pair`) allows the ISNS_P↔ISNS_N pair down to 0.15mm; clearance to every other net
  stays 0.2mm. `min_track_width` is 0.15mm. Single source of truth: `NET_WIDTHS["ISNS_P/N"] = 0.15`
  in `placement.py` (`local_finish` narrows to it, `validate_widths` checks it). **Do NOT claim
  0.1mm / 0.089mm — that is a 1oz spec and invalid on this 2oz board.**
- **⚠️ ISNS is NOT a tight matched pair after the re-route (first-spin limitation).** The router
  put ISNS_P on B.Cu (~57mm, along y≈81.6) and ISNS_N on a different corridor (~102mm, F.Cu detour
  east to x≈156 and back) — they never travel together, so the earlier "sits ~0.17mm apart, matched
  length" description is obsolete. Effect: a differential pickup loop that adds ~5–10 A of transient
  error on the **rising** edge of the pulse (peak/energy unaffected — see `ORDER_NOTES.md` bring-up
  item 5). A clean local re-author isn't possible — the only corridor paralleling ISNS_P is ~0.7mm
  wide (boxed by ISNS_P at x≈88.4 and ARM_SENSE at x≈89.1), so a proper pair needs a routing pass.
  **Rev-2 fix:** author the full ISNS pair (taps→INA240) as *locked critical copper in preroute* so
  the router routes everything else around it (same pattern as the SHUNT_HI bus / Kelvin ties), and
  **drop the now-moot `isns_kelvin_pair` scoped rule** from `.kicad_dru` — it describes the old
  co-routed pair (min same-layer separation is now 0.65 mm at the INA240 pins) and no longer applies.
- **Never enable a differential-pair router on ISNS** — it hard-couples at ~0.02mm
  (unmanufacturable) every time. Route sense pairs as normal matched nets.
- **Reference designators live on the F.Fab layer**, not silkscreen (dense board); LCSC part
  numbers are hidden property fields (still in the data for the BOM). Physical silk keeps only
  outlines + annotations (K=tab, gate G, polarity, board labels).
- **Voltage domains:** `VBANK` / `VBOOST` / `AUX_BANK` are the elevated rails (VBANK/AUX_BANK
  carry 1.0mm creepage clearance). `SHUNT_HI` is high-*current* but low-*voltage* (low-side
  shunt, near GND) — do **not** give it high-voltage clearance.
- **KiCad 10 API traps:** `PCB_VIA.GetWidth()` needs a layer arg (else blocking-assert hang);
  `board.Remove()` / a second `LoadBoard()` corrupt SWIG footprint wrappers (reload fresh).

## Validation (all green)
Run before any fab-package generation:
- `gen_pcb.py` DRC via `kicad-cli pcb drc --schematic-parity` → **0 electrical** (0 unconnected /
  shorts / clearance / parity), 16 cosmetic silk warnings only.
- `validate.py --production` → PASS (all parts placed; R24 = 6.8k 1W 2512, LCSC C26073).
- `validate_widths.py` → PASS (board matches `NET_WIDTHS`).
- `check_netlist.py` → all safety/topology assertions PASS.
- `calcs.py` → all design margins pass.

## Known items / explicit decisions
- **R24 (bank bleed) = 6.8k 1W 2512, LCSC `C26073`** (UNI-ROYAL 25121WJ0682T4E, in stock). The
  original "6.8k 2W" was inconsistent — a 2512 is a ~1W package and every stocked 6.8k 2512 is 1W
  (2W variants are out of stock). Dissipation is 0.44W (55²/6.8k), so 1W gives 2.2× margin. **JLC
  places it — no hand-install.**
- **WAIVER — gate-drive route lengths are unequal.** Measured DRV1/2/3 ≈ 33.2 / 10.1 / 9.0 mm and
  QG1/2/3 ≈ 28.9 / 24.0 / 23.5 mm, so Q10's total gate loop (~62mm) is ~2× Q11/Q12 (~33mm). Accepted
  because each paralleled FET has its **own gate resistor** (R34/R37/R40) that dominates the drive
  impedance, damps ringing, and balances turn-on; and this is a **µs-scale pulse** application, not
  fast PWM, so a small turn-on skew is tolerable. If tighter current-sharing is ever required,
  re-place/re-route to equalize the loops or scope the FET turn-on and adjust gate-R values.

## State & next step
- Committed. Renders: `hardware/fab/renders/driver_{top,bottom}.png`. DRC report: `hardware/fab/drc_driver.json`.
- **JLCPCB fab package generated** — `hardware/fab/jlc/` (`gen_fab.py`): `omnimarble-driver-gerbers.zip`
  (gerbers+drill), `bom_jlc.csv`, `cpl_jlc.csv`, `drc_driver.json`, and `ORDER_NOTES.md`. Scope is
  **SMT + THT assembly** (159 machine-placed incl. 12 THT; 8 hand-installed sockets/fuses/bulk-caps).
  Regenerate with `gen_fab.py`. Next action: upload to JLC and clear its DFM (see ORDER_NOTES).

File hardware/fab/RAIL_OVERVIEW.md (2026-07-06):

# OmniMarble Gate-Rail (sensor board) — Overview

> ⚠️ **vNext — on hold (2026-07-06).** This break-beam rail is **superseded** on the
> current path: V0 uses off-the-shelf **Waveshare ITR20001** reflective modules
> (before/after the coil) straight into the Pico, so no custom sensor board is built
> for V0 — see **[`../V0_BENCH_RIG.md`](../V0_BENCH_RIG.md)**. This board is DRC-clean
> and preserved; revisit if a spread-station rail is wanted after V0.

The **sense side** of the OmniMarble rig: an IR break-beam sensor rail that
detects the steel marble as it passes six stations along the coil track, so the
measured launch can be compared against the PINN simulation. It is the companion
to the driver board and plugs into the driver's J6 / J7 headers.

## What it is
- **224 × 15 mm, 2-layer, 1 oz** copper. Low-current board (~144 mA on +5 V from
  6 IR LEDs at ~24 mA; sub-mA signal lines), so 1 oz is ample — no 2 oz/4-layer
  like the driver. B.Cu is a solid GND pour; 2 vias (one +5 V, one SIG_SPARE→TP1).
- **6 sensor stations** at z = **-60 / -40 / -20 / +5 / +60 / +120 mm** from the
  coil-center fiducial. Exact x-spacing is asserted to 0.01 mm at board generation
  (`gen_rail_pcb.py`), silk-labelled `z=±NN` per station.

## One PCB, two population variants
Both circuits are drawn on the same board; assembly selects which parts are fitted
(each symbol carries a `Variant` field, and a silk `EMIT [ ] RECV [ ]` checkbox
marks the built board):
- **EMIT** — populate **D1–6** (IR333C-A 5 mm IR LEDs, C5130) + **R1–6** (150 Ω
  0603, C22808). Drive: `+5V → 150 Ω → LED → GND`.
- **RECV** — populate **Q1–6** (PT204-6B 3 mm phototransistors, C5133). Collector
  → `SIGx`, emitter → GND (pulled up on the driver).
- **COMMON** — **J1** (IDC-10, C5665). D and Q share each station footprint; only
  one is fitted per build.

A break-beam setup needs at least one EMIT board and one RECV board facing each
other across the track.

## Connection to the driver
`J1` (IDC-10) pinout:
```
1=+5V  2=GND  3..8=SIG1..6  9=SIG_SPARE  10=GND
```
This matches driver **J7 (RAIL-RECV) pin-for-pin** — J7 carries +5 V/GND *and* the
six SIG lines to the front-end. Driver **J6 (RAIL-EMIT)** is **power-only**
(alternating +5 V/GND on all 10 pins); the EMIT rail only uses J1.1/J1.2/J1.10,
and its SIG traces dead-end at the unpopulated Q pads, so J6 works for EMIT.
**Cables are not interchangeable: never plug a RECV board into J6** (its
phototransistor collectors would sit across +5 V/GND — non-damaging but no sense
data). Label the ribbons; the silk EMIT/RECV checkbox helps.

## How it is generated (fully scripted, deterministic, no autorouter)
1. `gen_gate_rail.py` → schematic (`gate-rail.kicad_sch`) + `.kicad_pro`
2. `kicad-cli sch export netlist` → `gate-rail.net`
3. `gen_rail_pcb.py` → board — places footprints (with parity metadata), hand-emits
   every track / via / GND pour, asserts station spacing, fills. Needs only KiCad's
   bundled Python + `pcbnew`.
4. `gen_fab.py rail` → per-variant fab package (below)

## Status
- ERC **0**; DRC `--schematic-parity` **0 parity / 0 electrical / 0 unconnected**
  (20 cosmetic silk warnings — dense station labels, same as any tight rail).
- Fab package (`hardware/fab/rail/`): 2-layer gerbers + drill, gbrjob 1 oz + rev
  `r1`, **two variant assemblies** — `cpl_rail_emit.csv` (D1-6 + R1-6 + J1 = 13)
  and `cpl_rail_recv.csv` (Q1-6 + J1 = 7) — plus `bom_rail_{emit,recv}.csv` and
  `ORDER_NOTES.md`.

## Ordering (JLC turnkey)
- Enable **THT assembly** (mixed board: the resistors are 0603 SMD; the IDC header,
  IR LEDs and phototransistors are through-hole).
- **One** bare-board gerber order; **two** assembly jobs (EMIT and RECV) — the two
  variants populate different parts on the same footprints, so a single CPL can't
  build both. See `hardware/fab/rail/ORDER_NOTES.md`.
</content>

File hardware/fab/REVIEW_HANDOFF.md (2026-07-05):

> ⚠️ **SUPERSEDED (2026-07-05).** This describes the mid-project freerouting
> attempt (13 unconnected). The board is now **fully routed and DRC-clean** via
> DeepPCB + local finish — see **`BOARD_OVERVIEW.md`** for the current handoff.
> Kept only for history.

# OmniMarble Driver PCB — Review Handoff (rev 3: autorouting pivot)

**Repo:** github.com/addisokw/omnimarble
**Board:** `hardware/omnimarble-driver/omnimarble-driver.kicad_pcb`
**Tool:** KiCad 10.0.4 + freerouting v2.2.4 (run on JDK 26)

## What changed since rev 2

We retired the from-scratch PathFinder router for bulk signal routing and pivoted
to **freerouting v2.2.4**. The earlier "freerouting is unusable" verdict was wrong
— its failures were fixable pipeline defects, not board complexity. New
reproducible pipeline: `preroute → dsn_fixup → freerouting → import-ses → DRC`.

**Key mechanism** (`hardware/scripts/dsn_fixup.py`, new): KiCad exports one flat
0.2 mm net class, so we post-process the DSN to (a) inject real per-width net
classes, (b) give pulse/bank nets the 1.0 mm bank-voltage clearance, (c) lock all
critical + pour copper `(type route)→(type fix)` so the router can't rip it.
`max_passes=30` (the 9999 default caused the prior ~700 GB / non-termination).
The same prepared DSN also uploads to DeepPCB unchanged (parallel option).

## Results (kicad-cli, `--schematic-parity`)

| Metric | Scripted (rev 2) | freerouting (now) |
|---|---|---|
| Unconnected | 118 | **13** |
| Clearance | 59 (to 0.010 mm on FIRE_GATED) | **6** (all mild 0.15 mm signal) |
| Shorts / crossings / parity | 0 / 0 / 0 | **0 / 0 / 0** |
| Hole-to-hole / hole-clearance | — | **0 / 0** |

The clearance quality is the material improvement: no more
sub-manufacturing-tolerance near-shorts on safety nets; the 6 remaining are benign
0.15 mm gaps on ADC-SPI / 3V3 / IMON_F.

## The 13 unconnected (honest categorization)

- **3 critical, unrouted by design**: SHUNT_HI Kelvin (×2), BST_G boost gate.
  Deterministic critical-net authoring (plan Step 1) was deferred to validate the
  freerouting pipeline first; these are exactly what that step authors and locks —
  which also satisfies the rev-2 requirement that critical nets be hand-finished,
  not autorouted.
- **5 GND**: congested fine-pitch pads the full-board GND pour + via-in-pad
  stitching couldn't reach.
- **5 signal taps**: 3V3 (U10), +5V, +24V (U2), VBANK_DIV (U3) in dense areas.

## Two decisions needing scrutiny

1. **Design-rule relaxation**: board min-via lowered 0.5→0.4 mm, min-hole
   0.3→0.2 mm (in `.kicad_pro`) to allow the 0.45/0.25 GND via-in-pad stitching.
   JLC-manufacturable, but a real rule change — please confirm acceptable for this
   board class.
2. **New architecture**: full-board F.Cu/B.Cu GND pours added (`build_zones`), so
   GND pads connect to the pour directly rather than each needing a threaded via.
   Standard practice, but it substantially changes the copper — worth confirming no
   unintended coupling into the analog / Kelvin / boost-sense sections.

## Still not fab-ready (unchanged gate from rev 2)

0 unconnected / 0 clearance / 0 parity, **then** manual power-loop / Kelvin / boost
review with net-highlighted screenshots (symmetric FET copper, true Kelvin pickup
at the shunt, intentional thermal reliefs on pulse pads), then silkscreen cleanup +
fab exports. Order-time gates still open: 6.8 k bleed LCSC C-number, relay NO/NC
continuity.

## What I want your opinion on

- Is the freerouted track geometry acceptable for the noncritical nets, given
  critical nets will be separately authored and locked?
- The min-via/hole relaxation and the full-board GND pour — any objection?
- Anything the DRC-clean copper is masking that a highlighted-net review should
  target first?

## Artifacts

- Renders: `hardware/fab/renders/driver_top.png`, `driver_bottom.png`
- Scorecard dashboard: `hardware/fab/driver_pcb_review.html`
- DRC report (regenerate): `kicad-cli pcb drc --schematic-parity --format json
  -o hardware/fab/drc_driver.json hardware/omnimarble-driver/omnimarble-driver.kicad_pcb`
- Pipeline scripts: `hardware/scripts/dsn_fixup.py`, `gen_pcb.py` (modes:
  preroute / import-ses / repair), `placement.py` (CRITICAL_NETS / PLANE_NETS /
  netclass_rules)

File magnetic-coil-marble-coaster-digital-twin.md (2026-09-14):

# Magnetic Coil Marble Roller Coaster — Digital Twin Implementation Plan

## Project overview

Build a digital twin of a magnetic coil-launched marble roller coaster using NVIDIA's simulation stack. The system simulates electromagnetic coil launchers accelerating a steel marble along a 3D-printed track, with the goal of predicting physical behavior digitally before building, and eventually running a live sim-to-real feedback loop.

### What we have

- **One STL file** of the roller coaster track (triangle mesh, no semantic separation, no physics)
- **No CAD model of the coil** — we need to generate a parametric solenoid geometry programmatically
- **Target marble**: ~10mm diameter steel ball bearing (density ~7800 kg/m³)
- **Target coil**: single-stage solenoid launcher (copper wire, ~20-40 turns, ~12-24V pulse)

### What we're building

1. **STL → OpenUSD pipeline** — convert the track mesh into a physics-ready USD scene
2. **Parametric coil generator** — programmatically create solenoid geometry in USD
3. **PhysicsNeMo PINN electromagnetic surrogate** — train a neural network on Maxwell's magnetostatic equations to predict B-field for any coil configuration in real-time
4. **PhysX rigid body simulation** — marble dynamics on the track with gravity, friction, contact
5. **Warp integration** — GPU-accelerated marble + EM force coupling, differentiable for optimization
6. **Omniverse scene** — composed USD layers for visualization and sim

---

## Phase 1: STL to OpenUSD conversion

### 1.1 Mesh preparation

The STL is raw triangle soup. Before converting, we need to clean and optionally split it.

**Dependencies**: `trimesh`, `numpy`, `pxr` (OpenUSD Python bindings)

```bash
pip install trimesh numpy --break-system-packages
```

For the `pxr` USD bindings, install via:
```bash
pip install usd-core --break-system-packages
```

**Steps**:

1. Load the STL with trimesh
2. Fix normals (ensure consistent winding)
3. Remove degenerate triangles (zero-area faces)
4. Optionally decimate if triangle count > 100k (for PhysX performance)
5. Identify and separate disconnected components (track sections, supports, etc.) using `trimesh.graph.connected_components`
6. Export each component as a separate mesh in the USD scene

```python
import trimesh
import numpy as np

mesh = trimesh.load("track.stl")
mesh.fix_normals()
mesh.remove_degenerate_faces()
mesh.remove_duplicate_faces()

# Split into connected components
components = mesh.split(only_watertight=False)
print(f"Found {len(components)} connected components")

# Identify the main track (largest component by face count)
track_mesh = max(components, key=lambda m: len(m.faces))
support_meshes = [m for m in components if m is not track_mesh]
```

### 1.2 Write to OpenUSD

Create a USD stage with proper units, up-axis, and the track mesh as a `UsdGeom.Mesh`.

**Critical**: STL files have no unit metadata. You must know what units your CAD software used. If the STL is in millimeters, set `metersPerUnit = 0.001`.

```python
from pxr import Usd, UsdGeom, UsdPhysics, Gf, Vt, Sdf

stage = Usd.Stage.CreateNew("marble_coaster.usda")

# Set scene metadata — CRITICAL: match your STL's units
UsdGeom.SetStageMetersPerUnit(stage, 0.001)  # if STL is in mm
UsdGeom.SetStageUpAxis(stage, UsdGeom.Tokens.z)  # match your CAD

# Create world root
world = UsdGeom.Xform.Define(stage, "/World")

# Create the track mesh
track_prim = UsdGeom.Mesh.Define(stage, "/World/Track")
track_prim.CreatePointsAttr(Vt.Vec3fArray([Gf.Vec3f(*v) for v in track_mesh.vertices]))
track_prim.CreateFaceVertexCountsAttr(Vt.IntArray([3] * len(track_mesh.faces)))
track_prim.CreateFaceVertexIndicesAttr(Vt.IntArray(track_mesh.faces.flatten().tolist()))
track_prim.CreateSubdivisionSchemeAttr("none")  # keep triangles as-is

# Compute and set normals
normals = track_mesh.vertex_normals
track_prim.CreateNormalsAttr(Vt.Vec3fArray([Gf.Vec3f(*n) for n in normals]))
track_prim.SetNormalsInterpolation("vertex")

# Set extent (bounding box)
bounds = track_mesh.bounds
track_prim.CreateExtentAttr(Vt.Vec3fArray([
    Gf.Vec3f(*bounds[0]), Gf.Vec3f(*bounds[1])
]))

stage.GetRootLayer().Save()
```

### 1.3 Apply physics schemas to the track

The track is a **static collider** — it doesn't move, but the marble collides with it.

```python
# Make the track a static collider using exact triangle mesh
track_p = stage.GetPrimAtPath("/World/Track")
UsdPhysics.CollisionAPI.Apply(track_p)
mesh_collision = UsdPhysics.MeshCollisionAPI.Apply(track_p)
mesh_collision.GetApproximationAttr().Set("none")  # exact triangle mesh, no simplification

# Create a physics scene
physics_scene = UsdPhysics.Scene.Define(stage, "/World/PhysicsScene")
physics_scene.CreateGravityDirectionAttr(Gf.Vec3f(0, 0, -1))
physics_scene.CreateGravityMagnitudeAttr(9810.0)  # mm/s² if stage is in mm
```

### 1.4 Create the marble

The marble is a **dynamic rigid body** with a sphere collider.

```python
# Marble transform
marble_xform = UsdGeom.Xform.Define(stage, "/World/Marble")
marble_xform.AddTranslateOp().Set(Gf.Vec3d(0, 0, 50))  # starting position (adjust)

# Marble visual geometry
marble_geom = UsdGeom.Sphere.Define(stage, "/World/Marble/Geom")
marble_geom.CreateRadiusAttr(5.0)  # 5mm radius = 10mm diameter marble

# Rigid body API on the Xform (parent)
rb = UsdPhysics.RigidBodyAPI.Apply(marble_xform.GetPrim())

# Collision API on the sphere geometry
UsdPhysics.CollisionAPI.Apply(marble_geom.GetPrim())

# Mass properties
mass_api = UsdPhysics.MassAPI.Apply(marble_xform.GetPrim())
mass_api.CreateDensityAttr(7.8e-3)  # steel density in g/mm³ (7800 kg/m³)
```

### 1.5 Physics materials

```python
# Track material (PLA/resin surface)
track_mat_path = "/World/Materials/TrackMaterial"
track_mat_prim = stage.DefinePrim(track_mat_path)
track_phys_mat = UsdPhysics.MaterialAPI.Apply(track_mat_prim)
track_phys_mat.CreateStaticFrictionAttr(0.4)
track_phys_mat.CreateDynamicFrictionAttr(0.3)
track_phys_mat.CreateRestitutionAttr(0.3)  # low bounce on track

# Marble material (steel)
marble_mat_path = "/World/Materials/MarbleMaterial"
marble_mat_prim = stage.DefinePrim(marble_mat_path)
marble_phys_mat = UsdPhysics.MaterialAPI.Apply(marble_mat_prim)
marble_phys_mat.CreateStaticFrictionAttr(0.5)
marble_phys_mat.CreateDynamicFrictionAttr(0.35)
marble_phys_mat.CreateRestitutionAttr(0.6)  # steel bounces moderately

# Bind materials (using UsdShade binding)
from pxr import UsdShade
UsdShade.MaterialBindingAPI.Apply(stage.GetPrimAtPath("/World/Track")).Bind(
    UsdShade.Material(track_mat_prim))
UsdShade.MaterialBindingAPI.Apply(stage.GetPrimAtPath("/World/Marble/Geom")).Bind(
    UsdShade.Material(marble_mat_prim))
```

### 1.6 PhysX simulation tuning for the marble

```python
from pxr import PhysxSchema

# Enable CCD on the marble (critical — small fast object after launch)
physx_rb = PhysxSchema.PhysxRigidBodyAPI.Apply(marble_xform.GetPrim())
physx_rb.CreateEnableCCDAttr(True)

# Increase contact offset slightly for better contact detection on curved track
physx_col = PhysxSchema.PhysxCollisionAPI.Apply(marble_geom.GetPrim())
physx_col.CreateContactOffsetAttr(2.0)  # 2mm contact offset
physx_col.CreateRestOffsetAttr(0.0)

# Configure the physics scene for accurate marble simulation
physx_scene = PhysxSchema.PhysxSceneAPI.Apply(physics_scene.GetPrim())
physx_scene.CreateTimeStepsPerSecondAttr(120)  # 120 Hz minimum for small marble
physx_scene.CreateEnableCCDAttr(True)
# TGS solver is the default in PhysX 5.x — no explicit setting needed
# It applies friction every iteration, which gives smooth rolling behavior

stage.GetRootLayer().Save()
```

---

## Phase 2: Parametric coil generator

Since we don't have a coil CAD model, we generate one programmatically. The coil is a solenoid — a helical winding of wire around a cylindrical bore.

### 2.1 Coil geometry parameters

```python
# Coil parameters (adjust to your physical build)
COIL_PARAMS = {
    "inner_radius": 8.0,      # mm — must be > marble radius (5mm) + clearance
    "outer_radius": 14.0,     # mm — wire winding thickness
    "length": 30.0,           # mm — coil length along axis
    "num_turns": 30,          # number of wire turns
    "wire_diameter": 0.8,     # mm — wire gauge (AWG 20 ≈ 0.8mm)
    "coil_position": [0, 0, 20],  # mm — center position on track
    "coil_axis": [1, 0, 0],   # direction the marble travels through
}
```

### 2.2 Generate coil mesh

Create a simplified cylindrical shell representation (not individual wire turns — that's for the EM solver, not the visual/collision mesh).

```python
def create_coil_mesh(stage, path, params):
    """Create a cylindrical coil housing as a USD mesh."""
    import math

    r_inner = params["inner_radius"]
    r_outer = params["outer_radius"]
    length = params["length"]
    n_segments = 32  # circumferential resolution

    # Generate vertices for inner and outer cylinders, top and bottom caps
    verts = []
    faces = []
    counts = []

    for i in range(n_segments):
        angle = 2 * math.pi * i / n_segments
        cos_a, sin_a = math.cos(angle), math.sin(angle)

        # 4 rings: inner-bottom, inner-top, outer-bottom, outer-top
        verts.append(Gf.Vec3f(0, r_inner * cos_a, r_inner * sin_a))           # 0: inner bottom
        verts.append(Gf.Vec3f(length, r_inner * cos_a, r_inner * sin_a))      # 1: inner top
        verts.append(Gf.Vec3f(0, r_outer * cos_a, r_outer * sin_a))           # 2: outer bottom
        verts.append(Gf.Vec3f(length, r_outer * cos_a, r_outer * sin_a))      # 3: outer top

    # Generate quad faces connecting adjacent segments
    for i in range(n_segments):
        j = (i + 1) % n_segments
        base_i = i * 4
        base_j = j * 4

        # Outer wall
        faces.extend([base_i + 2, base_j + 2, base_j + 3, base_i + 3])
        counts.append(4)
        # Inner wall
        faces.extend([base_i + 0, base_i + 1, base_j + 1, base_j + 0])
        counts.append(4)
        # Bottom cap
        faces.extend([base_i + 0, base_j + 0, base_j + 2, base_i + 2])
        counts.append(4)
        # Top cap
        faces.extend([base_i + 1, base_i + 3, base_j + 3, base_j + 1])
        counts.append(4)

    coil_mesh = UsdGeom.Mesh.Define(stage, path)
    coil_mesh.CreatePointsAttr(Vt.Vec3fArray(verts))
    coil_mesh.CreateFaceVertexCountsAttr(Vt.IntArray(counts))
    coil_mesh.CreateFaceVertexIndicesAttr(Vt.IntArray(faces))
    coil_mesh.CreateSubdivisionSchemeAttr("none")

    # Position the coil
    xform = UsdGeom.Xformable(coil_mesh.GetPrim())
    xform.AddTranslateOp().Set(Gf.Vec3d(*params["coil_position"]))

    # Static collider (marble passes through the bore, but can hit the housing)
    UsdPhysics.CollisionAPI.Apply(coil_mesh.GetPrim())
    col = UsdPhysics.MeshCollisionAPI.Apply(coil_mesh.GetPrim())
    col.GetApproximationAttr().Set("convexDecomposition")

    return coil_mesh
```

### 2.3 Store coil parameters as USD custom attributes

These custom properties let the simulation code read coil specs directly from the USD scene.

```python
coil_prim = stage.GetPrimAtPath("/World/Coil")

# Custom attributes for the EM solver to read
coil_prim.CreateAttribute("coilLauncher:numTurns", Sdf.ValueTypeNames.Int).Set(30)
coil_prim.CreateAttribute("coilLauncher:wireGauge_mm", Sdf.ValueTypeNames.Float).Set(0.8)
coil_prim.CreateAttribute("coilLauncher:innerRadius_mm", Sdf.ValueTypeNames.Float).Set(8.0)
coil_prim.CreateAttribute("coilLauncher:length_mm", Sdf.ValueTypeNames.Float).Set(30.0)
coil_prim.CreateAttribute("coilLauncher:maxCurrent_A", Sdf.ValueTypeNames.Float).Set(10.0)
coil_prim.CreateAttribute("coilLauncher:pulseWidth_ms", Sdf.ValueTypeNames.Float).Set(5.0)
coil_prim.CreateAttribute("coilLauncher:resistance_ohm", Sdf.ValueTypeNames.Float).Set(1.2)
coil_prim.CreateAttribute("coilLauncher:inductance_uH", Sdf.ValueTypeNames.Float).Set(150.0)
```

---

## Phase 3: PhysicsNeMo PINN electromagnetic surrogate

Train a physics-informed neural network to predict the magnetic field of the solenoid for any configuration, enabling real-time EM force computation during simulation.

### 3.1 Problem formulation

The coil launcher is a **magnetostatic** problem (quasi-static — current pulse is slow vs speed of light). We solve in 2D axisymmetric cylindrical coordinates (r, z) exploiting the solenoid's rotational symmetry.

**Governing equations** (magnetostatic Maxwell in cylindrical coords):

- ∇ × **B** = μ₀**J** (Ampere's law)
- ∇ · **B** = 0 (divergence-free)

In terms of the magnetic vector potential **A** (where **B** = ∇ × **A**), for axisymmetric problems the only nonzero component is A_φ, and the PDE becomes:

```
-∂²A_φ/∂r² - (1/r)∂A_φ/∂r + A_φ/r² - ∂²A_φ/∂z² = μ₀ J_φ(r,z)
```

where J_φ is the current density (nonzero only inside the coil winding region).

### 3.2 PINN architecture

**Inputs**: (r, z, I, N, R_coil, L_coil) — position + coil parameters
**Outputs**: (A_φ, B_r, B_z) — vector potential and field components
**Hidden layers**: 6 layers × 256 neurons, sin activation (good for oscillatory fields)

```python
# PhysicsNeMo Sym setup (pseudocode — adapt to current API)
from physicsnemo.sym.hydra import instantiate_arch, PhysicsNeMoConfig
from physicsnemo.sym.solver import Solver
from physicsnemo.sym.domain import Domain
from physicsnemo.sym.key import Key

# Network architecture
net = instantiate_arch(
    input_keys=[Key("r"), Key("z"), Key("I"), Key("N"), Key("R"), Key("L")],
    output_keys=[Key("A_phi"), Key("B_r"), Key("B_z")],
    cfg={
        "arch_type": "fully_connected",
        "layer_size": 256,
        "nr_layers": 6,
        "activation_fn": "sin",
    }
)
```

### 3.3 Loss function components

```python
# 1. PDE residual loss (interior of domain)
#    -d²A/dr² - (1/r)dA/dr + A/r² - d²A/dz² = mu0 * J(r,z)
#    Sampled at ~10,000 random (r,z) points per batch

# 2. Divergence-free constraint
#    ∂B_r/∂r + B_r/r + ∂B_z/∂z = 0
#    (enforced as soft constraint on the B outputs)

# 3. Boundary conditions
#    A_phi → 0 as r,z → ∞ (far-field decay)
#    A_phi = 0 at r = 0 (symmetry axis)
#    B_r = 0 at r = 0 (axial symmetry)

# 4. Curl consistency
#    B_r = -∂A_phi/∂z
#    B_z = (1/r)∂(r*A_phi)/∂r
#    (ensures B outputs are consistent with A output)

# 5. Optional: data loss from FEM reference solutions or measurements
#    If you have COMSOL/FEMM solutions, add as supervision anchors
```

### 3.4 Training configuration

```python
# Domain bounds (in mm)
DOMAIN = {
    "r": (0, 100),        # radial extent (0 to 10× coil radius)
    "z": (-150, 150),     # axial extent (±5× coil length)
}

# Parameter ranges for the parameterized PINN
PARAM_RANGES = {
    "I": (0.5, 20.0),     # current in amps
    "N": (10, 60),        # number of turns
    "R": (6.0, 20.0),     # inner radius in mm
    "L": (15.0, 60.0),    # coil length in mm
}

# Training
TRAINING = {
    "max_steps": 100_000,
    "batch_size": 4096,
    "learning_rate": 1e-3,
    "lr_scheduler": "cosine_annealing",
    "interior_points_per_step": 10000,
    "boundary_points_per_step": 2000,
    "coil_region_points_per_step": 3000,  # extra density in coil region
}
```

### 3.5 Force computation from the trained PINN

Once trained, the PINN predicts B(r,z) for any coil config in ~1ms. The force on the ferromagnetic marble is:

```python
def compute_marble_force(pinn, marble_pos, marble_radius, coil_params):
    """
    Compute electromagnetic force on a ferromagnetic sphere.

    F = (χ_eff * V / μ₀) * ∇(B²/2)

    where:
    - χ_eff = effective susceptibility of steel (~200 for mild steel)
    - V = (4/3)πr³ = marble volume
    - B = magnetic flux density from PINN
    - ∇(B²/2) = B_r * ∂B_r/∂r + B_z * ∂B_z/∂z (gradient of field energy)
    """
    r, z = marble_pos  # axisymmetric coordinates
    I, N, R, L = coil_params

    # Query PINN (differentiable — can compute gradients)
    B_r, B_z = pinn.predict(r, z, I, N, R, L)

    # Compute field gradient (automatic differentiation through PINN)
    dBr_dr, dBr_dz = pinn.gradient(B_r, r, z)
    dBz_dr, dBz_dz = pinn.gradient(B_z, r, z)

    # Force on ferromagnetic sphere
    chi_eff = 3.0  # EFFECTIVE susceptibility of a sphere: demagnetisation caps it
                   # at 3 for any high-permeability material (a material chi of
                   # ~200 would over-predict the force ~67x). See scripts/rlc_circuit.py.
    mu0 = 4 * np.pi * 1e-7  # T·m/A (convert to mm units in implementation)
    V = (4/3) * np.pi * marble_radius**3

    # F = (χV/μ₀) * (B · ∇)B
    F_r = (chi_eff * V / mu0) * (B_r * dBr_dr + B_z * dBr_dz)
    F_z = (chi_eff * V / mu0) * (B_r * dBz_dr + B_z * dBz_dz)

    return F_r, F_z
```

---

## Phase 4: Warp GPU simulation kernel

NVIDIA Warp provides the glue between the PINN EM model and the PhysX rigid body dynamics, running on GPU with full differentiability.

### 4.1 Dependencies

```bash
pip install warp-lang --break-system-packages
```

### 4.2 Marble dynamics kernel

```python
import warp as wp

@wp.struct
class CoilParams:
    position: wp.vec3     # coil center in world coords
    axis: wp.vec3         # coil axis direction (normalized)
    current: wp.float32   # instantaneous current (A)
    num_turns: wp.int32
    inner_radius: wp.float32
    length: wp.float32

@wp.struct
class MarbleState:
    position: wp.vec3
    velocity: wp.vec3
    angular_velocity: wp.vec3
    radius: wp.float32
    mass: wp.float32

@wp.kernel
def compute_em_force_kernel(
    marble: wp.array(dtype=MarbleState),
    coils: wp.array(dtype=CoilParams),
    num_coils: wp.int32,
    em_force: wp.array(dtype=wp.vec3),  # output
    dt: wp.float32,
):
    """Compute electromagnetic force on the marble from all coils."""
    tid = wp.tid()

    m = marble[tid]
    total_force = wp.vec3(0.0, 0.0, 0.0)

    for c in range(num_coils):
        coil = coils[c]

        # Transform marble position to coil-local cylindrical coords
        rel = m.position - coil.position
        along_axis = wp.dot(rel, coil.axis)  # z in coil frame
        perp = rel - along_axis * coil.axis
        r = wp.length(perp)  # radial distance from coil axis

        # Query PINN surrogate for B-field (placeholder — actual PINN inference here)
        # In practice, this calls into a pre-trained model or lookup table
        B_z, B_r, dBz_dz, dBr_dr = evaluate_bfield(
            r, along_axis, coil.current, coil.num_turns,
            coil.inner_radius, coil.length
        )

        # Force on ferromagnetic sphere: F = (χV/μ₀)(B·∇)B
        chi_eff = 3.0  # sphere-effective value; demagnetisation-capped (see above)
        mu0 = 1.2566e-3  # μ₀ in mm-scale units (T·mm/A * conversion)
        V = 4.0 / 3.0 * 3.14159 * m.radius * m.radius * m.radius

        coeff = chi_eff * V / mu0
        F_axial = coeff * (B_r * dBz_dr + B_z * dBz_dz)   # (B·∇)B_z
        F_radial = coeff * (B_r * dBr_dr + B_z * dBr_dz)  # (B·∇)B_r

        # Transform back to world coordinates
        force_world = F_axial * coil.axis
        if r > 0.01:
            radial_dir = perp / r
            force_world = force_world + F_radial * radial_dir

        total_force = total_force + force_world

    em_force[tid] = total_force
```

### 4.3 Coil current pulse model

The coil current isn't constant — it follows an LR circuit discharge profile.

```python
@wp.func
def coil_current_pulse(
    t: wp.float32,             # time since trigger (ms)
    V_supply: wp.float32,      # supply voltage (V)
    R: wp.float32,             # coil resistance (Ω)
    L: wp.float32,             # coil inductance (H)
    pulse_width: wp.float32,   # how long switch is closed (ms)
) -> wp.float32:
    """LR circuit current: I(t) = (V/R)(1 - e^(-Rt/L)) during pulse, then decay."""
    tau = L / R  # time constant in seconds
    t_sec = t * 0.001  # convert ms to seconds
    pw_sec = pulse_width * 0.001

    if t_sec < 0.0:
        return 0.0
    elif t_sec < pw_sec:
        # Rising phase
        return (V_supply / R) * (1.0 - wp.exp(-t_sec / tau))
    else:
        # Decay phase after switch opens
        I_peak = (V_supply / R) * (1.0 - wp.exp(-pw_sec / tau))
        return I_peak * wp.exp(-(t_sec - pw_sec) / tau)
```
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

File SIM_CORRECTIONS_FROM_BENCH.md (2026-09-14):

# Sim corrections from bench measurement (2026-07-26)

Findings from characterising the physical demo coil and pulse loop on the
`omnimarble-vbench` board. **Nothing here has been changed yet** — this is the
change list, written while the measurements are fresh.

Measurement provenance: 4-wire LCR (FNIRSI LC1020E), a gate-on-time discharge
sweep on the real hardware, and DC current injection. See
`../omnimarble-vbench/docs/REV_B_NOTES.md` for the raw values and method.

---

## S-1 — `mean_radius` is computed from the wrong geometry — **the big one**

`CoilPhysics.recompute_derived()` builds **two different mean radii** and uses
the wrong one for the circuit model:
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

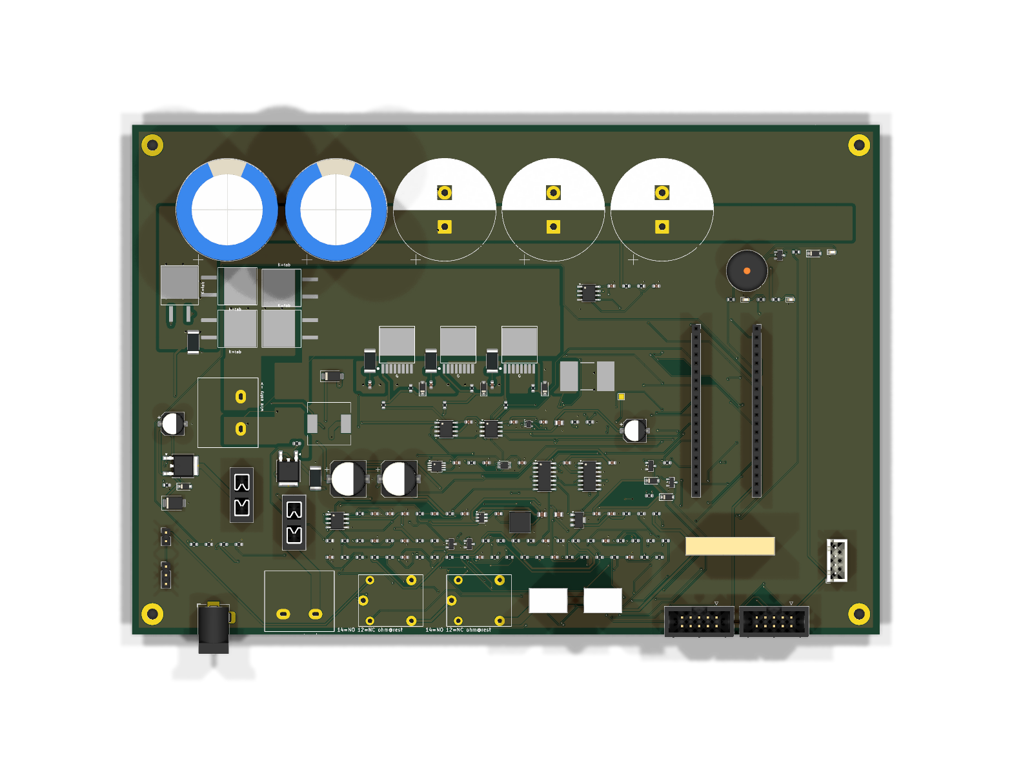
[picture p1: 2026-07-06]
hardware/fab/renders/driver_top.png

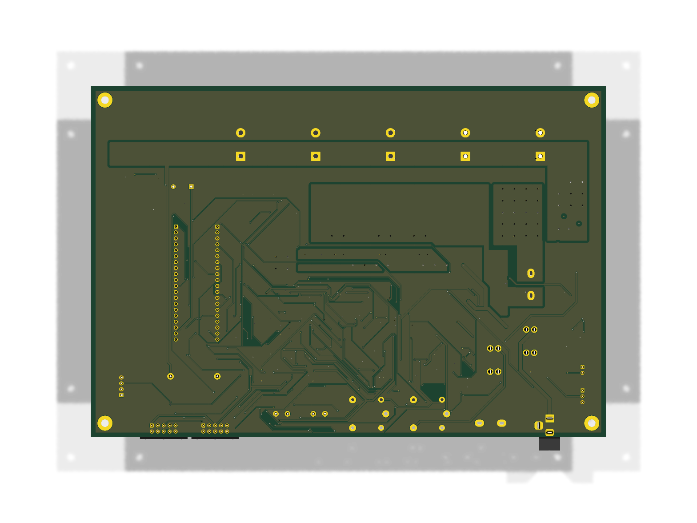
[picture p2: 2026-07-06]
hardware/fab/renders/driver_bottom.png

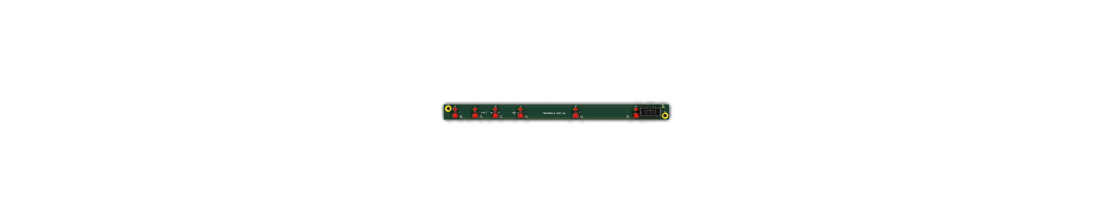
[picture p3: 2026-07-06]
hardware/fab/renders/gate-rail_top.png

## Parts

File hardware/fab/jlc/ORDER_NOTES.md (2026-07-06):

# OmniMarble Driver — JLCPCB Order Notes

Assembly package for `omnimarble-driver.kicad_pcb`. **Scope: SMT + THT
assembly** (JLC places surface-mount *and* the common through-hole parts).

## Board
- 220 × 150 mm, **4-layer, 2 oz outer / 1 oz inner** copper, **ENIG** finish
  (F.Cu / In1.GND / In2.GND / B.Cu). The stackup + gerber job metadata state this.
- Min track/space 0.15 mm; min via 0.4 mm / 0.2 mm drill
- Electrical DRC: **0** (0 unconnected / shorts / clearance / parity). 16 cosmetic
  silk warnings only. Report: `drc_driver.json`.

## Files in this package
| File | Upload to |
|---|---|
| `omnimarble-driver-gerbers.zip` | JLC **fabrication** (gerbers + drill) |
| `bom_jlc.csv` | JLC **assembly** — BOM (54 line items) |
| `cpl_jlc.csv` | JLC **assembly** — pick-and-place (159 placements) |
| `drc_driver.json` | reference (DRC evidence) |

Summary: **159 machine-placed** parts, **8 hand-installed**,
7 board features, 3 do-not-populate.

## When ordering (read first)
1. **Set 4-layer, 2 oz OUTER copper + ENIG finish.** The thermal/current design
   assumes 2 oz outer; verify the order form matches (the gerber stackup states it,
   but the copper weight is a paid order-form selection). ENIG is recommended for
   the fine-pitch U10.
2. **Enable "Assemble top side" + turn ON through-hole assembly** — 12 of the
   placed parts are THT (below). Without THT assembly JLC will skip them.
3. **Verify component rotations in JLC's preview.** KiCad and JLC differ on some
   part rotations (polarised caps, some ICs/connectors). **Check K1/K2 especially**
   — both relays are at rotation 0 in the CPL and JLC's relay origin convention
   often differs from KiCad's; a wrong relay rotation swaps its terminals. Also
   confirm J1 (barrel jack) and the polarised caps. Fix any flagged in JLC's
   online CPL editor before paying.
4. **Let JLC's DFM be the final arbiter.** Inspect DFM warnings around **U10**
   (fine-pitch ADS7042 escape), **U2**, the **ISNS_P/N traces** (0.15 mm width —
   intentional, 2 oz min; note these are *not* a tight matched pair — see bring-up
   item 5), and **J1** (barrel jack is now an **edge-mount** — its body overhangs
   the bottom outline ~6 mm by design; pads are on-board).

## Machine-placed through-hole parts (need JLC THT assembly) — 12
| Ref | Value | LCSC (package) |
|---|---|---|
| BZ1 | buzzer-5V | C409842 (Buzzer_12x9.5RM7.6) |
| J1 | 24V-IN | C381116 (BarrelJack_Horizontal) |
| J2 | AUX-BANK | C707836 (TerminalBarrier_1x02_P9.50mm) |
| J5 | COIL | C707836 (TerminalBarrier_1x02_P9.50mm) |
| J6 | RAIL-EMIT | C5665 (IDC-Header_2x05_P2.54mm_Vertical) |
| J7 | RAIL-RECV | C5665 (IDC-Header_2x05_P2.54mm_Vertical) |
| J8 | SPARE-JST | C144395 (JST_XH_B4B-XH-A_1x04_P2.50mm_Vertical) |
| K1 | HF3FF-12V | C399561 (Relay_HF3FF_T73) |
| K2 | HF3FF-12V | C399561 (Relay_HF3FF_T73) |
| R19 | 47R-5W | C5807995 (R_Box_L26.0mm_W5.0mm_P20.00mm) |
| R21 | 100R-10W | C5110275 (R_Radial_Power_L11.0mm_W7.0mm_P5.00mm) |
| R22 | 100R-10W | C5110275 (R_Radial_Power_L11.0mm_W7.0mm_P5.00mm) |

## Hand-installed by you (NOT on the CPL) — 8
Order these separately (LCSC # given where known) and solder after JLC assembly.
| Ref | Value | LCSC (package) |
|---|---|---|
| C90 | 2200u-63V | C3724971 (CP_Radial_D30.0mm_P10.00mm_SnapIn) |
| C91 | 2200u-63V | C3724971 (CP_Radial_D30.0mm_P10.00mm_SnapIn) |
| F1 | 5A-MINI | C5249699 (Fuseholder_Blade_Mini_Keystone_3568) |
| F2 | 30A-MINI | C5249699 (Fuseholder_Blade_Mini_Keystone_3568) |
| J10 | PICO-SOCKET | C50984 (PinSocket_1x20_P2.54mm_Vertical) |
| J3 | E-STOP-NC | — (PinHeader_1x02_P2.54mm_Vertical) |
| J4 | ARM-KEY | — (PinHeader_1x03_P2.54mm_Vertical) |
| J9 | PICO-SOCKET | C50984 (PinSocket_1x20_P2.54mm_Vertical) |

## Board features (no placement) — 7
| Ref | Value |
|---|---|
| H1 | MountingHole_3.2mm_M3_Pad |
| H2 | MountingHole_3.2mm_M3_Pad |
| H3 | MountingHole_3.2mm_M3_Pad |
| H4 | MountingHole_3.2mm_M3_Pad |
| NT1 | NetTie |
| NT2 | NetTie |
| TP1 | DRV_SPARE |

## Do-not-populate — 3
| Ref | Value |
|---|---|
| C92 | 2200u-63V |
| C93 | 2200u-63V |
| C94 | 2200u-63V |

## Bring-up checklist (physical checks DRC/parity CANNOT catch)
1. **Ohmmeter each relay (K1, K2) de-energized: COM↔NC continuity.** The HF3FF
   footprint's NO/NC were transposed and fixed by a pad-number swap — parity is
   green *by construction*, so a meter is the ONLY confirmation the dump/charge
   logic isn't inverted. De-energized, COM must read to NC (not NO).
2. **OVP is a *throttle*, not a hard stop — the authoritative over-voltage cut
   is firmware.** U5's TL431 cathode sits on the UC3843 COMP pin and can only
   clamp it to ~2–2.5 V, which *reduces* the charge current but does not reach
   zero duty (that needs COMP < 1.4 V). So on a bench supply the observable is a
   **charge-rate knee near ~59–62 V with continued slow creep**, NOT a clean
   plateau — a tester expecting a hard stop could mis-judge a working part.
   **Firmware MUST treat VBANK_SENSE > threshold as a hard `BOOST_EN_N` inhibit**
   (drives Q1, which saturates COMP to ~0.1 V and has full authority). Verify
   *that* interlock, and the analog knee, before the first bank charge.
   *(Rev-2: give the TL431 full authority via a PNP off BST_VREF onto COMP/Q1.)*
3. **Fan-cool U2 (78L12, SOT-89) and watch its temp** during a sustained charge
   — it runs hot (~0.5–0.85 W); the DPAK thermal upgrade was deferred.
4. Stage first power at the **25 V floor**, then up to 55 V, verifying boost
   regulation before installing max bank capacitance or firing into the coil.
5. **Current-sense rise-phase caveat (ISNS).** The re-route left ISNS_P and
   ISNS_N on different corridors (not a tight pair), so during the fast dI/dt at
   pulse onset expect ~5–10 A of transient pickup error on the *rising* edge;
   **peak and energy readings are unaffected.** For first-spin sim-to-real
   comparison, trust peak/energy; treat the rise-phase waveform as indicative.
   (Rev-2 fix: pre-author the ISNS pair as locked critical copper.)

---
*Generated by `hardware/scripts/gen_fab.py` from the committed board.*

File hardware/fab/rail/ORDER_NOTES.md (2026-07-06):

# OmniMarble Gate-Rail (sensor board) — JLCPCB Order Notes

Assembly package for `gate-rail.kicad_pcb` — the IR break-beam sensor rail. **One
PCB, two population variants**; order the bare board once, then assemble as many
**EMIT** and **RECV** boards as your setup needs (a break-beam needs at least one
of each, plugged into the driver's J6 (RAIL-EMIT) / J7 (RAIL-RECV) headers).

## Board
- **224 × 15 mm, 2-layer, 1 oz** copper (low-current IR rail: ~144 mA on +5 V at
  ~24 mA/LED, sub-mA signals — 1 oz is ample). HASL or ENIG both fine.
- 6 sensor stations at z = -60 / -40 / -20 / +5 / +60 / +120 mm from the coil
  fiducial (silk-labelled; spacing asserted to 0.01 mm at board generation).
- IDC-10 (J1): `1=+5V 2=GND 3..8=SIG1..6 9=SIG_SPARE 10=GND` — matches driver **J7**
  pin-for-pin; driver **J6** is power-only (alternating +5V/GND), so a RECV board
  must never plug into J6. Label the ribbons.
- Electrical DRC **0** (0 unconnected / parity); silk warnings cosmetic. `drc_rail.json`.

## Files in this package
| File | Upload to |
|---|---|
| `gate-rail-gerbers.zip` | JLC **fabrication** (gerbers + drill) |
| `bom_rail_emit.csv` + `cpl_rail_emit.csv` | JLC **assembly** — EMIT variant (13 parts) |
| `bom_rail_recv.csv` + `cpl_rail_recv.csv` | JLC **assembly** — RECV variant (7 parts) |
| `drc_rail.json` | reference (DRC evidence) |

## When ordering (read first)
1. **Mixed SMD + THT — turn ON THT assembly.** The 150 Ω resistors are 0603 SMD;
   the IDC header, 5 mm IR LEDs and 3 mm phototransistors are through-hole. Without
   THT assembly JLC skips the through-hole parts.
2. **One gerber zip, but two assembly orders.** Fab the shared bare board, then run
   the EMIT CPL/BOM and the RECV CPL/BOM as **separate assembly jobs** — the two
   variants populate different parts on the *same* footprints, so a single CPL
   can't build both. Order however many of each you need.
3. **EMIT** populates D1–6 (IR333C-A) + R1–6 (150 Ω) + J1. **RECV** populates
   Q1–6 (PT204-6B) + J1. D and Q share each station; only one is fitted per build.
4. **Silk marks the built variant** — check the `EMIT [ ] RECV [ ]` box on each
   board so populated boards are distinguishable at assembly.
5. **🔴 CONFIRM OPTO POLARITY IN THE ASSEMBLY PREVIEW (mandatory gate).** The
   Everlight IR333C-A and PT204-6B number pin 1 as anode / emitter — *opposite*
   KiCad's generic `Device:LED` / `Q_Photo` convention. The board is wired
   correctly for **flat-to-flat** insertion (footprint pad 1 = flat-marked side:
   D cathode→GND, anode→LEDA; Q collector→SIG, emitter→GND), so JLC's polarity
   orientation places them right — **but verify it in the preview before paying**:
   each D's flat/cathode faces GND (away from its resistor), each Q's flat/collector
   faces its SIG trace. If the preview shows them reversed, rotate 180° in JLC's
   editor. (Do not have the *generator* swap the nets — that reverses a correct board.)
6. **Verify rotations in JLC's preview** (the IDC header especially), and let JLC's
   DFM be the final arbiter.

## EMIT variant — machine-placed — 13 parts, 13 placements
| Ref | Value | LCSC (package) | Type |
|---|---|---|---|
| D1 | IR333C-A | C5130 (LED_D5.0mm) | THT |
| D2 | IR333C-A | C5130 (LED_D5.0mm) | THT |
| D3 | IR333C-A | C5130 (LED_D5.0mm) | THT |
| D4 | IR333C-A | C5130 (LED_D5.0mm) | THT |
| D5 | IR333C-A | C5130 (LED_D5.0mm) | THT |
| D6 | IR333C-A | C5130 (LED_D5.0mm) | THT |
| J1 | RAIL-IDC | C5665 (IDC-Header_2x05_P2.54mm_Vertical) | THT |
| R1 | 150 | C22808 (R_0603_1608Metric) | SMD |
| R2 | 150 | C22808 (R_0603_1608Metric) | SMD |
| R3 | 150 | C22808 (R_0603_1608Metric) | SMD |
| R4 | 150 | C22808 (R_0603_1608Metric) | SMD |
| R5 | 150 | C22808 (R_0603_1608Metric) | SMD |
| R6 | 150 | C22808 (R_0603_1608Metric) | SMD |

## RECV variant — machine-placed — 7 parts, 7 placements
| Ref | Value | LCSC (package) | Type |
|---|---|---|---|
| J1 | RAIL-IDC | C5665 (IDC-Header_2x05_P2.54mm_Vertical) | THT |
| Q1 | PT204-6B | C5133 (LED_D3.0mm) | THT |
| Q2 | PT204-6B | C5133 (LED_D3.0mm) | THT |
| Q3 | PT204-6B | C5133 (LED_D3.0mm) | THT |
| Q4 | PT204-6B | C5133 (LED_D3.0mm) | THT |
| Q5 | PT204-6B | C5133 (LED_D3.0mm) | THT |
| Q6 | PT204-6B | C5133 (LED_D3.0mm) | THT |

## Hand-installed / not on the CPL
| Ref | Value | LCSC (package) |
|---|---|---|
| — | none | — |

---
*Generated by `hardware/scripts/gen_fab.py rail` from the committed board.*

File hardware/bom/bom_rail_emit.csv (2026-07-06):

Reference | Value | Footprint | LCSC
D1 | IR333C-A | LED_THT:LED_D5.0mm | C5130
D2 | IR333C-A | LED_THT:LED_D5.0mm | C5130
D3 | IR333C-A | LED_THT:LED_D5.0mm | C5130
D4 | IR333C-A | LED_THT:LED_D5.0mm | C5130
D5 | IR333C-A | LED_THT:LED_D5.0mm | C5130
D6 | IR333C-A | LED_THT:LED_D5.0mm | C5130
J1 | RAIL-IDC | Connector_IDC:IDC-Header_2x05_P2.54mm_Vertical | C5665
R1 | 150 | Resistor_SMD:R_0603_1608Metric | C22808
R2 | 150 | Resistor_SMD:R_0603_1608Metric | C22808
R3 | 150 | Resistor_SMD:R_0603_1608Metric | C22808
R4 | 150 | Resistor_SMD:R_0603_1608Metric | C22808
R5 | 150 | Resistor_SMD:R_0603_1608Metric | C22808
R6 | 150 | Resistor_SMD:R_0603_1608Metric | C22808

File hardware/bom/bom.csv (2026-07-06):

key | mfr | mpn | lcsc | jlc_class | package | qty | description | alternate
fet_pulse | SCILICON | SFT040N150C3 | C42395334 | ext | TOLL | 3 | 150V 4.0mOhm(max) NFET, ID(pulse) 760A | NCEP15T14LL (C2686615, TOLL 150V 5.8mOhm IDM 680A)
diode_pulse | YFW | MBR60100DC | C6069541 | ext | TO-263 | 5 | 100V 60A Schottky, IFSM 450A (blocking x2, freewheel x2, bank clamp x1) | MBR40100DC-B (C5359198, low stock)
shunt | Yezhan | ASR-M-7-0.2F | C469442 | ext | 5930 | 1 | 0.2mOhm 1% 15W metal element (Kelvin PCB routing) | HolRS3920-5W-0.2mR-1% (C558625); Bourns CSS2H-3920R-L200FE (C4126121, low stock)
cap_bank | Nichicon | LKG1J222MESBBK | C3724971 | hand | snap-in 30x30mm | 2 | 2200uF 63V snap-in; 5 positions, populate 2 baseline (4400uF), max 11000uF | Chengx radial 18mm 2200uF/63V (C47858)
term_coil | Kangnex | HB9500-9.5-02P-13-00A | C60785 | ext-tht | 9.5mm barrier | 2 | 32A barrier terminal, coil + aux-bank connections (pulse path) | Wurth REDCUBE M4 (hand-install, not LCSC)
fuse_aux | Littelfuse | 0997030.WXN | C207030 | hand | MINI blade | 1 | 30A 58VDC MINI blade fuse, aux-bank feed; holder Keystone 3568 | ATO 0287030.PXCN (C142686, 32V - marginal)
boost_ctrl | onsemi | UC3843BD1R2G | C16414 | ext | SOIC-8 | 1 | Current-mode boost controller, 24.5-55V operating (63V-rated bank) @ ~0.5A, Vcc from +12V rail | LM3481MMX/NOPB (C543002; needs custom symbol)
boost_fet | AOS | AOD66923 | C485687 | ext | TO-252 | 1 | 100V 11mOhm boost switch | UMW 15N10 (C359106)
boost_diode | MDD | SS510 | C65010 | ext | SMA | 1 | 100V 5A Schottky, boost rectifier | SS510B (C7420368, SMB, preferred-class)
boost_ind | YJYCOIN | YSPI1365-470M | C497913 | ext | 1265 | 1 | 47uH 5A/7Asat shielded power inductor | APH1265T470M (C5349639)
relay | Hongfa | HF3FF/012-1ZS | C399561 | ext-tht | THT relay | 2 | 12V coil SPDT 15A (charge + dump), NO contact used | HF115F/012-1HS3 (C61377, 16A, lower stock)
tl431 | TI | TL431BIDBZR | C41283 | ext | SOT-23-3 | 1 | Shunt ref +/-0.5%, DBZ pinout (1=K,2=REF,3=A) -- matches the TL431DBZ footprint. OVP trip 60.5V nom (59.1-62.0V band). NOT CJ431/C3113 (that part is 1=REF,2=K,3=A -> OVP dead); NOT the 1% A-grade (would blow the 62.0V ceiling) | CD431 +/-0.5% (JSCJ, same 1=K,2=REF,3=A pinout)
buck5 | Diodes | AP63205WU-7 | C2071056 | ext | TSOT-23-6 | 1 | 24V->5V/2A buck (logic + Pico VSYS + gate emitters) | TPS54331DR (C9865, preferred-class)
reg12 | UMW | 78L12(UMW) | C347272 | ext | SOT-89 | 1 | 24V->12V linear, gate-driver + relay rail. THERMAL FOLLOW-UP: ~0.5-0.85W during charge is hot for SOT-89 -- upgrade to 78M12 TO-252/DPAK (Shikues C116325) in a dedicated re-place/re-route pass | 78M12 TO-252 C116325 (thermal upgrade, needs re-route)
tvs_in | MDD | SMBJ26CA | C113996 | ext | SMB | 1 | 24V input TVS, bidirectional (matches D_TVS symbol); 26V standoff clamps below SMBJ33A -- confirm vs AP63205 VIN abs-max | STMicro SMBJ26CA-TR (C133665)
fuse_in | Littelfuse | 0997005.WXN | C2680609 | hand | MINI blade | 1 | 5A input fuse (holder hand-installed; confirm PN at order) | any 5A MINI blade
pfet_rpp | AOS | AOD4185 | C77317 | ext | TO-252 | 1 | -40V PFET reverse-polarity protection (confirm stock at order) | any 40V+ PFET, TO-252
jack24 | XKB | DC-005-5A-2.0 | C381116 | ext-tht | DC barrel 5.5/2.1 | 1 | 24V input jack (5A, 24V rated - input only) | 5.08mm terminal WJ128V-5.0-2P (C8269)
gate_drv | TI | UCC27524ADR | C185857 | ext | SOIC-8 | 2 | Dual 5A low-side gate driver (per-FET gate resistors) | UCC27524DR (C465729)
and_gate | TI | SN74LVC1G08DCKR | C7832 | ext | SC-70-5 | 1 | FIRE = MCU_FIRE AND ARM (hardware interlock) | SN74LVC1G08DBVR (C7666, SOT-23-5)
gate_clamp | - | BZT52C15 | C19077412 | ext | SOD-123 | 3 | 15V gate clamp zener per FET | SMAJ15A (C19077535)
ina240 | TI | INA240A1PWR | C93965 | ext | TSSOP-8 | 1 | Current-sense amp, gain 20 (0.2mOhm -> 4mV/A) | INA240A2PWR (C129949, gain 50 - would clip)
adc | TI | ADS7042IDCUR | C701641 | ext | VSSOP-8 | 1 | 12-bit 1MSPS SPI ADC for I(t) capture | ADS7886SBDBVR (C2669886, SOT-23-6)
opamp | Microchip | MCP6002T-I/SN | C7377 | ext | SOIC-8 | 1 | RRIO dual op-amp: V_bank + 24V sense buffers | LMV358IDR (C63813)
comparator | TI | LM339DR | C7948 | ext | SOIC-14 | 2 | Quad comparator x2: 6 IR gate channels + live-bank detect | LM339DR2G (C63821)
ir_led | Everlight | IR333C-A | C5130 | ext-tht | 5mm THT | 6 | 940nm IR emitter (gate-rail EMIT variant) | IR204C-A-L (C98863, 3mm)
ir_pt | Everlight | PT204-6B | C5133 | ext-tht | 3mm THT | 6 | 940nm NPN phototransistor (gate-rail RECV variant) | PT333-3C (C264295, OUT OF STOCK 2026-07)
idc10 | BOOMELE | 2.54-2*5P box header | C5665 | ext-tht | IDC 2x5 | 4 | Sensor-rail ribbon headers (2 on driver, 1 per rail) | any shrouded 2x5 2.54mm
jst_xh4 | JST | B4B-XH-A(LF)(SN) | C144395 | ext-tht | JST-XH 4p | 1 | Spare ad-hoc sensor connector | B4B-XH-AM (C161871)
r_precharge | VO | SQM5W-47R-5% | C5807995 | ext-tht | cement THT | 1 | 47R 5W precharge across charge-relay contacts | TyOhm SMW 5W 47R (C2937346, SMD)
r_dump | CCO | CR-M10W100RJ | C216413 | ext-tht | cement THT | 2 | 100R 10W x2 in series = 200R/20W dump (5.3s to <5V) | RX27-4V 20W from Digi-Key if single-part preferred
r_bleed | UNI-ROYAL | 25121WJ0682T4E | C26073 | ext | 2512 1W | 1 | 6.8k permanent bleed (0.44W cont, 2.2x margin). 1W is the 2512 land rating; 1.5W/2W 2512 are all 0-stock on LCSC | C340514 (RMC1-682JTE-M) or C42372225, both 6.8k 2512 1W in stock
r_boost_cs | Milliohm | HoJLR2512-3W-150mR-1% | C2903485 | ext | 2512 3W | 1 | 0.15ohm boost switch current sense (~6.7A limit; was 0.05ohm/20A, above realistic inductor saturation) | TA-I RLP25FEER150 (C459673)
cap_boost_out | Honor | RVT1J101M1010 | C28241 | ext | SMD 10x10.2 | 2 | 100uF 63V boost output x2 (ripple: datasheet check at order) | Lelon VE-101M1JTR-1010 (C249468)
cap_bulk_35v | Lelon | VEJ101M1VTR-0607 | C176666 | ext | SMD 6.3x7.7 | 2 | 100uF 35V input bulk + armed-rail reservoir
ind_buck | Sunlord | SWPA6045S100MT | C79272 | ext | 6x6x4.5 | 1 | 10uH Isat 3.5A, 5V buck output | SWPA5040S100MT (C84608)
buzzer | Fengming | YS-MBZ12085C05R42 | C409842 | ext-tht | 12mm THT | 1 | 5V passive electromagnetic buzzer | MLT-8530 SMD (C94599, 2.5-4.5V)
fuse_holder | Keystone | Keystone 3568 | C5249699 | ext-tht | MINI clip THT | 4 | MINI blade fuse holder (2 clips per fuse position)
pico_socket | BOOMELE | 2.54-1*20P female | C50984 | ext-tht | THT | 2 | Raspberry Pi Pico socket (Pico bought separately)
io_breakout | Ckmtw | B-2100S40P-B110 2x20 breakaway | C124383 | ext-tht | THT | 1 | MCU-agnostic IO breakout (parallel with Pico socket)
arm_key | - | key switch SPST |  | hand | panel | 1 | ARM keyswitch (panel-mount, wired to header)

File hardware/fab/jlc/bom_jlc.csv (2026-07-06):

Comment | Designator | Footprint | LCSC Part # | Qty
10k | R3,R4,R5,R11,R13,R14,R17,R29,R31,R32,R33,R35,R38,R41,R44,R45,R46,R48,R50,R52,R54,R56,R58,R60,R62,R64,R66,R68 | R_0603_1608Metric | C25804 | 28
1k | R8,R18,R20,R23,R47,R51,R55,R59,R63,R67,R70,R71,R72 | R_0603_1608Metric | C21190 | 13
100n | C2,C6,C8,C9,C16,C17,C20,C26,C29,C36,C37 | C_0603_1608Metric | C14663 | 11
1n | C7,C11,C27,C30,C31,C32,C33,C34,C35 | C_0603_1608Metric | C1588 | 9
100k | R1,R2,R9,R10,R15,R26 | R_0603_1608Metric | C25803 | 6
1u | C5,C14,C15,C21,C22,C28 | C_0603_1608Metric | C15849 | 6
220k | R49,R53,R57,R61,R65,R69 | R_0603_1608Metric | C22961 | 6
10R | R6,R34,R37,R40,R43 | R_0603_1608Metric | C22859 | 5
MBR60100DC | D9,D10,D11,D12,D13 | D2PAK_MBR60100DC | C6069541 | 5
10n | C10,C23,C24,C25 | C_0603_1608Metric | C57112 | 4
BZT52C15 | D1,D6,D7,D8 | D_SOD-123 | C19077412 | 4
MMBT3904 | Q1,Q2,Q3,Q4 | SOT-23 | C20526 | 4
10u | C3,C4,C18 | C_0805_2012Metric | C15850 | 3
1N4148W | D3,D4,D16 | D_SOD-123 | C81598 | 3
4.7R | R36,R39,R42 | R_2512_6332Metric | C25489 | 3
SFT040N150C3 | Q10,Q11,Q12 | TOLL-8 | C42395334 | 3
100R-10W | R21,R22 | R_Radial_Power_L11.0mm_W7.0mm_P5.00mm | C5110275 | 2
100u-35V | C1,C19 | CP_Elec_6.3x7.7 | C176666 | 2
100u-63V | C12,C13 | CP_Elec_10x10.5 | C28241 | 2
27k | R28,R30 | R_0603_1608Metric | C22967 | 2
HF3FF-12V | K1,K2 | Relay_HF3FF_T73 | C399561 | 2
LED_red | D5,D14 | LED_0603_1608Metric | C2286 | 2
LM339 | U11,U12 | SOIC-14_3.9x8.7mm_P1.27mm | C7948 | 2
UCC27524A | U7,U8 | SOIC-8_3.9x4.9mm_P1.27mm | C185857 | 2
0.15R-2512 | R7 | R_2512_6332Metric | C2903485 | 1
0.2m | RS1 | Shunt_5930 | C469442 | 1
10uH | L1 | L_Changjiang_FNR6045S | C79272 | 1
24V-IN | J1 | BarrelJack_Horizontal | C381116 | 1
4.3k | R16 | R_0603_1608Metric | C23159 | 1
47R-5W | R19 | R_Box_L26.0mm_W5.0mm_P20.00mm | C5807995 | 1
47k | R25 | R_0603_1608Metric | C25819 | 1
47uH | L2 | L_12x12mm_H8mm | C497913 | 1
5.1k | R27 | R_0603_1608Metric | C23186 | 1
6.8k | R24 | R_2512_6332Metric | C26073 | 1
74LVC1G08 | U6 | SOT-353_SC-70-5 | C7832 | 1
78L12 | U2 | SOT-89-3 | C347272 | 1
9.1k | R12 | R_0603_1608Metric | C23260 | 1
ADS7042 | U10 | VSSOP-8_2.3x2mm_P0.5mm | C701641 | 1
AOD4185 | Q90 | TO-252-2 | C5371006 | 1
AOD66923 | Q91 | TO-252-2 | C485687 | 1
AP63205 | U1 | TSOT-23-6 | C2071056 | 1
AUX-BANK | J2 | TerminalBarrier_1x02_P9.50mm | C707836 | 1
COIL | J5 | TerminalBarrier_1x02_P9.50mm | C707836 | 1
INA240A1 | U9 | TSSOP-8_3x3mm_P0.65mm | C93965 | 1
LED_green | D15 | LED_0603_1608Metric | C2289 | 1
MCP6002 | U3 | SOIC-8_3.9x4.9mm_P1.27mm | C7377 | 1
RAIL-EMIT | J6 | IDC-Header_2x05_P2.54mm_Vertical | C5665 | 1
RAIL-RECV | J7 | IDC-Header_2x05_P2.54mm_Vertical | C5665 | 1
SMBJ26CA | D90 | D_SMB | C113996 | 1
SPARE-JST | J8 | JST_XH_B4B-XH-A_1x04_P2.50mm_Vertical | C144395 | 1
SS510 | D2 | D_SMA | C65010 | 1
TL431B | U5 | SOT-23 | C41283 | 1
UC3843B | U4 | SOIC-8_3.9x4.9mm_P1.27mm | C2995531 | 1
buzzer-5V | BZ1 | Buzzer_12x9.5RM7.6 | C409842 | 1

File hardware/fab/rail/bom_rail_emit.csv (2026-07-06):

Comment | Designator | Footprint | LCSC Part # | Qty
150 | R1,R2,R3,R4,R5,R6 | R_0603_1608Metric | C22808 | 6
IR333C-A | D1,D2,D3,D4,D5,D6 | LED_D5.0mm | C5130 | 6
RAIL-IDC | J1 | IDC-Header_2x05_P2.54mm_Vertical | C5665 | 1

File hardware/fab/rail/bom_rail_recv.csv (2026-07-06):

Comment | Designator | Footprint | LCSC Part # | Qty
PT204-6B | Q1,Q2,Q3,Q4,Q5,Q6 | LED_D3.0mm | C5133 | 6
RAIL-IDC | J1 | IDC-Header_2x05_P2.54mm_Vertical | C5665 | 1

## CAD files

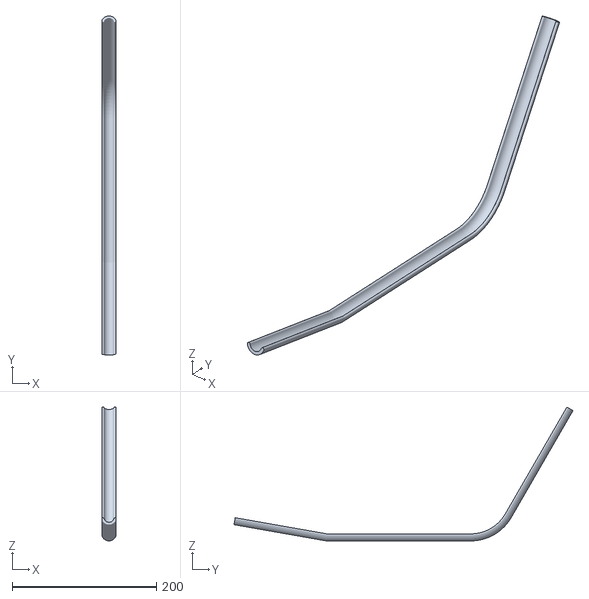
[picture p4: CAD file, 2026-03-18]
data/track-starter-slope.stl
20.1 x 470.0 x 185.5

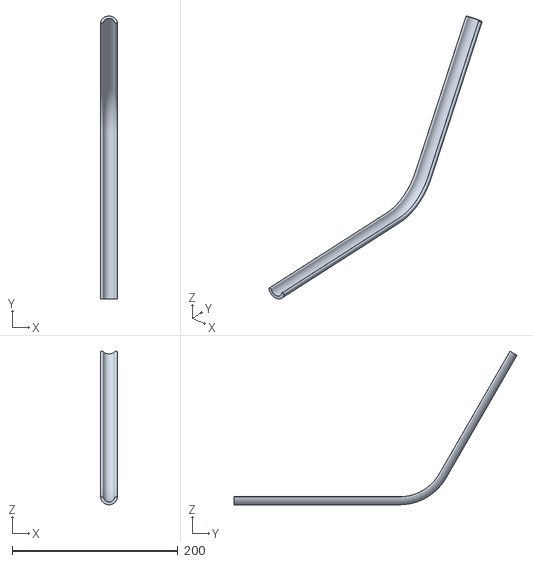
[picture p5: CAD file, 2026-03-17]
data/track.stl
20.1 x 341.8 x 185.5

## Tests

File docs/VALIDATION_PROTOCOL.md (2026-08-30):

# Validation protocol — how this sim avoids becoming a lookup table

The risk being managed: a model with enough adjustable constants can "agree"
with any finite dataset without containing any physics. This project has
fitted several constants to bench data (that is proper — the bench is the
arbiter), so the protection cannot be "never fit". It is these four rules.

## 1. Predictions are frozen before data exists

Every new configuration (can count, voltage regime, marble, geometry change)
gets predictions committed to git BEFORE the first shot, with per-point bands
and the meaning of each possible miss declared in advance. The commit hash is
the timestamp. Precedent: `docs/PREDICTION_3CAN.md` (67b6f37) — which caught
two real misses and is the reason the droop and knee physics were found at
all. A prediction written after the data is a description, not a test.

## 2. No constant is scored against the data that produced it

Every fitted constant must name its training data, and any agreement claim
made on that same data must be labelled IN-SAMPLE. Current ledger:

| constant | fitted to | independent corroboration | may be scored on |
|---|---|---|---|
| pulse C/R pairs (1/2/3 can) | blank-fire V(t) | LCR small-signal + droop trend | marble data, scope I(t) |
| freewheel tau 275 us | 3-can marble dv at 3 gates | implied R fits under measured loop R | 4/5-can data, other axes |
| PINN field factor (none applied) | — | marble dv via injected current | everything |

The "field within ~1.4%" figure is CONDITIONAL on the tau fit's form; the
unconditional bound from the injection campaign alone is ~2.5–5%. Say which
one is meant.

## 3. Every fitted quantity needs a second, mechanism-independent handle

tau has the loop-R consistency check; pulse C has the LCR + charge-balance
check; L and loop R have the waveform slope/peak extractions. The FIELD has
exactly one handle (marble dv) — closing that is the highest-value open item:

> **Hall-probe spot check**: small DC current through the coil, Hall sensor
> at surveyed positions, compare the PINN's absolute B directly. No marble,
> no circuit, no dynamics — an unconditional field measurement for ~$10.

Untested model choices to keep on the books: chi_eff = 3.0, B_sat, the
finite-size quadrature. Each should eventually get its own handle or an
explicit uncertainty band.

## 4. The C-sweep is a HOLDOUT, not a tuning set

Every constant in the model as of tag `model-freeze-3can` derives from
1–3 can data. Before can 4 is soldered:

1. Preregister 4-can and 5-can predictions (blanks + marble points) from the
   frozen model, per rule 1.
2. After the data: score, publicly, misses included. Fitting anything NEW to
   4-can data resets the holdout to 5 cans.

Held-out axes that no fit has consumed, usable at 3 cans any time:
- fire-position curve (the model says the peak stays at −13.5 ± 1 mm),
- a 30 V marble point,
- a different (weighed) marble,
- scope captures at 2 cans retrodicted with zero refits.

## The standing test

If the model only works where it was tuned, it will fail rule 4's first
encounter with can 4 — and that failure must be reported as loudly as the
successes. The preregistration record is only worth something because it can
contain misses; `PREDICTION_3CAN.md` already does.

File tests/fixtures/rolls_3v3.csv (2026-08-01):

wall_iso | pass_id | n_ch | v_mps | resid_us | dir | lead0_us | trail0_us | lead1_us | trail1_us | lead2_us | trail2_us | lead3_us | trail3_us | lead4_us | trail4_us | dwell0_us | dwell1_us | dwell2_us | dwell3_us | dwell4_us | gapv01_mps | gapv12_mps | gapv23_mps | gapv34_mps
2026-08-01T11:46:20 | 1.0 | 5.0 | 0.2702 | 26546.9 | rev | 319548.0 | 337720.0 | 275156.0 | 295312.0 | 217752.0 | 243932.0 | 137748.0 | 176328.0 | 0.0 | 66884.0 | 18172.0 | 20156.0 | 26180.0 | 38580.0 | 66884.0 | 0.49873851144350334 | 0.3856874085429587 | 0.2767361631918404 | 0.16072828643610074
2026-08-01T11:46:20 | 2.0 | 5.0 | 0.2353 | 38368.4 | fwd | 0.0 | 108844.0 | 180536.0 | 218392.0 | 258464.0 | 286048.0 | 315120.0 | 335444.0 | 364020.0 | 382768.0 | 108844.0 | 37856.0 | 27584.0 | 20324.0 | 18748.0 | 0.12263482075597111 | 0.28410840776101015 | 0.3907794408359221 | 0.452760736196319
2026-08-01T11:46:21 | 3.0 | 5.0 | 0.408 | 15243.7 | rev | 214572.0 | 229012.0 | 180280.0 | 195724.0 | 140096.0 | 157924.0 | 88136.0 | 112712.0 | 0.0 | 41160.0 | 14440.0 | 15444.0 | 17828.0 | 24576.0 | 41160.0 | 0.6456316342003967 | 0.5509655584312164 | 0.42609699769053117 | 0.2512026867568304
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

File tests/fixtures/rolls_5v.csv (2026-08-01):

wall_iso | pass_id | n_ch | v_mps | resid_us | dir | lead0_us | trail0_us | lead1_us | trail1_us | lead2_us | trail2_us | lead3_us | trail3_us | lead4_us | trail4_us | dwell0_us | dwell1_us | dwell2_us | dwell3_us | dwell4_us | gapv01_mps | gapv12_mps | gapv23_mps | gapv34_mps
2026-08-01T11:23:16 | 1.0 | 2.0 | 0.0913 |  | rev |  |  |  |  |  |  | 242448.0 | 336260.0 | 0.0 | 113612.0 |  |  |  | 93812.0 | 113612.0 |  |  |  | 0.09131855078202336
2026-08-01T11:23:17 | 2.0 | 1.0 |  |  | fwd | 0.0 | 173912.0 |  |  |  |  |  |  |  |  | 173912.0
2026-08-01T11:23:18 | 3.0 | 5.0 | 0.2923 | 31716.6 | fwd | 0.0 | 87704.0 | 145244.0 | 179120.0 | 210188.0 | 233404.0 | 253828.0 | 270660.0 | 291212.0 | 306352.0 | 87704.0 | 33876.0 | 23216.0 | 16832.0 | 15140.0 | 0.15243314698025393 | 0.3409090909090909 | 0.507332722273144 | 0.5922319708966403
2026-08-01T11:23:21 | 4.0 | 3.0 | 0.1089 | 44218.9 | fwd | 0.0 | 163968.0 | 279384.0 | 338420.0 | 377936.0 |  |  |  |  |  | 163968.0 | 59036.0 |  |  |  | 0.07924576926380895 | 0.22465297507914603
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

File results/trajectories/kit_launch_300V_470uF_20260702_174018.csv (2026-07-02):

# source=omni.marble.coaster Kit extension (PhysX + PINN)
# charge_voltage_V=300.0
# capacitance_uF=470.0
# num_turns=30
# chi_eff=3.0
# inductance_uH=12.4061
# R_total_ohm=0.11021
# stored_energy_J=21.15
# rlc_regime=underdamped
# pinn_checkpoint=pinn_best.pt
# pinn_step=250000
# pinn_derived_b=True
# approach_velocity_mm_s=208.33
# exit_velocity_mm_s=937.5
# boost_ratio=4.5
# gate_vel_in_1_t_s=0.194
# gate_vel_in_2_t_s=0.29
# gate_entry_t_s=0.386
# gate_cutoff_t_s=0.418
# gate_vel_out_1_t_s=0.482
# gate_vel_out_2_t_s=0.546
t_s | x_mm | y_mm | z_mm | z_along_mm | r_mm | vx_mm_s | vy_mm_s | vz_mm_s | vel_axial_mm_s | current_A | V_cap_V | F_z_mN | F_r_mN | Bz_T | wire_temp_C | triggered | pulse_cut
0.002 | 0.3135 | -20.0 | 12.0 | -79.4235 | 7.0 | 0.0 | 0.0 | 0.0 | 0.0 | 0.0 | 300.0 | 0.0 | 0.0 | 0.0 | 20.0 | 0 | 0
0.004 | 0.3135 | -20.0 | 12.0 | -79.4235 | 7.0 | 0.0 | 0.0 | 0.0 | 0.0 | 0.0 | 300.0 | 0.0 | 0.0 | 0.0 | 20.0 | 0 | 0
0.006 | 0.3135 | -20.0 | 12.0 | -79.4235 | 7.0 | 0.0 | 0.0 | 0.0 | 0.0 | 0.0 | 300.0 | 0.0 | 0.0 | 0.0 | 20.0 | 0 | 0
0.008 | 0.3135 | -20.0 | 12.0 | -79.4235 | 7.0 | 0.0 | 0.0 | 0.0 | 0.0 | 0.0 | 300.0 | 0.0 | 0.0 | 0.0 | 20.0 | 0 | 0
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

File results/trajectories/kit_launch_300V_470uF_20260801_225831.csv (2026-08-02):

# source=omni.marble.coaster Kit extension (PhysX + PINN)
# charge_voltage_V=300.0
# capacitance_uF=470.0
# num_turns=30
# chi_eff=3.0
# inductance_uH=12.4061
# R_total_ohm=0.11021
# stored_energy_J=21.15
# rlc_regime=underdamped
# pinn_checkpoint=pinn_best.pt
# pinn_step=250000
# pinn_derived_b=True
# approach_velocity_mm_s=208.33
# exit_velocity_mm_s=937.5
# boost_ratio=4.5
# gate_vel_in_1_t_s=0.194
# gate_vel_in_2_t_s=0.29
# gate_entry_t_s=0.386
# gate_cutoff_t_s=0.418
# gate_vel_out_1_t_s=0.482
# gate_vel_out_2_t_s=0.546
t_s | x_mm | y_mm | z_mm | z_along_mm | r_mm | vx_mm_s | vy_mm_s | vz_mm_s | vel_axial_mm_s | current_A | V_cap_V | F_z_mN | F_r_mN | Bz_T | wire_temp_C | triggered | pulse_cut
0.002 | 0.3135 | -20.0 | 12.0 | -79.4235 | 7.0 | 0.0 | 0.0 | 0.0 | 0.0 | 0.0 | 300.0 | 0.0 | 0.0 | 0.0 | 20.0 | 0 | 0
0.004 | 0.3135 | -20.0 | 12.0 | -79.4235 | 7.0 | 0.0 | 0.0 | 0.0 | 0.0 | 0.0 | 300.0 | 0.0 | 0.0 | 0.0 | 20.0 | 0 | 0
0.006 | 0.3135 | -20.0 | 12.0 | -79.4235 | 7.0 | 0.0 | 0.0 | 0.0 | 0.0 | 0.0 | 300.0 | 0.0 | 0.0 | 0.0 | 20.0 | 0 | 0
0.008 | 0.3135 | -20.0 | 12.0 | -79.4235 | 7.0 | 0.0 | 0.0 | 0.0 | 0.0 | 0.0 | 300.0 | 0.0 | 0.0 | 0.0 | 20.0 | 0 | 0
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

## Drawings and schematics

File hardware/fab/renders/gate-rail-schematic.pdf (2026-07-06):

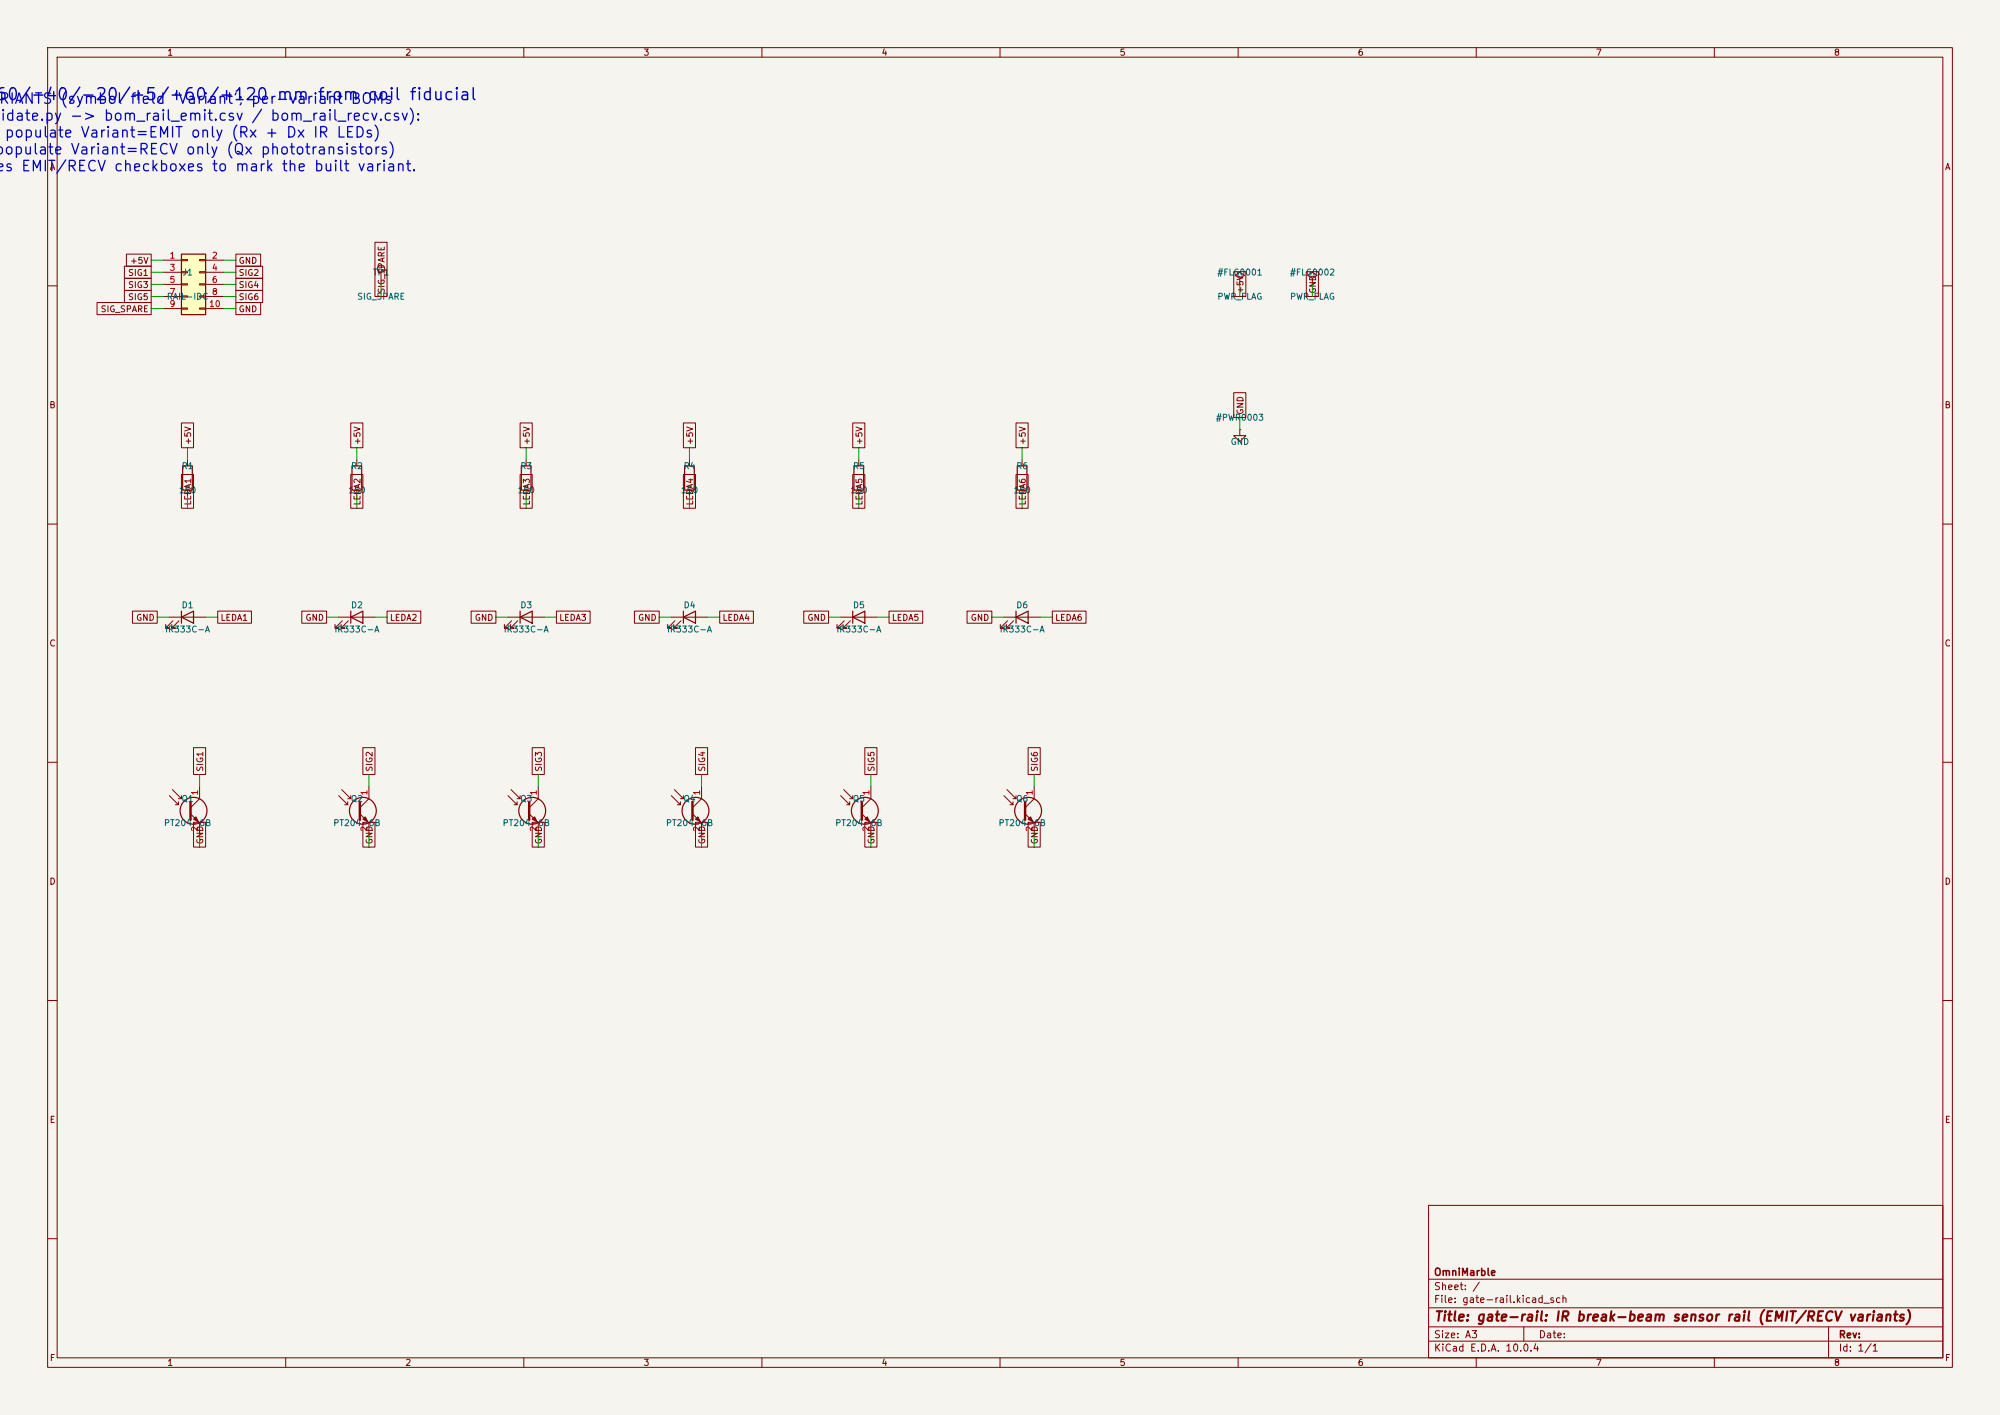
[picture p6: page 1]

6 stations at z = -60/-40/-20/+5/+60/+120 mm from coil fiducial

ASSEMBLY VARIANTS (symbol field 'Variant'; per-variant BOMs
generated by validate.py -> bom_rail_emit.csv / bom_rail_recv.csv):

EMIT rail: populate Variant=EMIT only (Rx + Dx IR LEDs)
RECV rail: populate Variant=RECV only (Qx phototransistors)
Silkscreen carries EMIT/RECV checkboxes to mark the built variant.

OmniMarble
Sheet: /
File: gate-rail.kicad_sch
Title: gate-rail: IR break-beam sensor rail (EMIT/RECV variants)

Size: A3 | Rev:
KiCad E.D.A. 10.0.4 | Id: 1/1 | F Date:

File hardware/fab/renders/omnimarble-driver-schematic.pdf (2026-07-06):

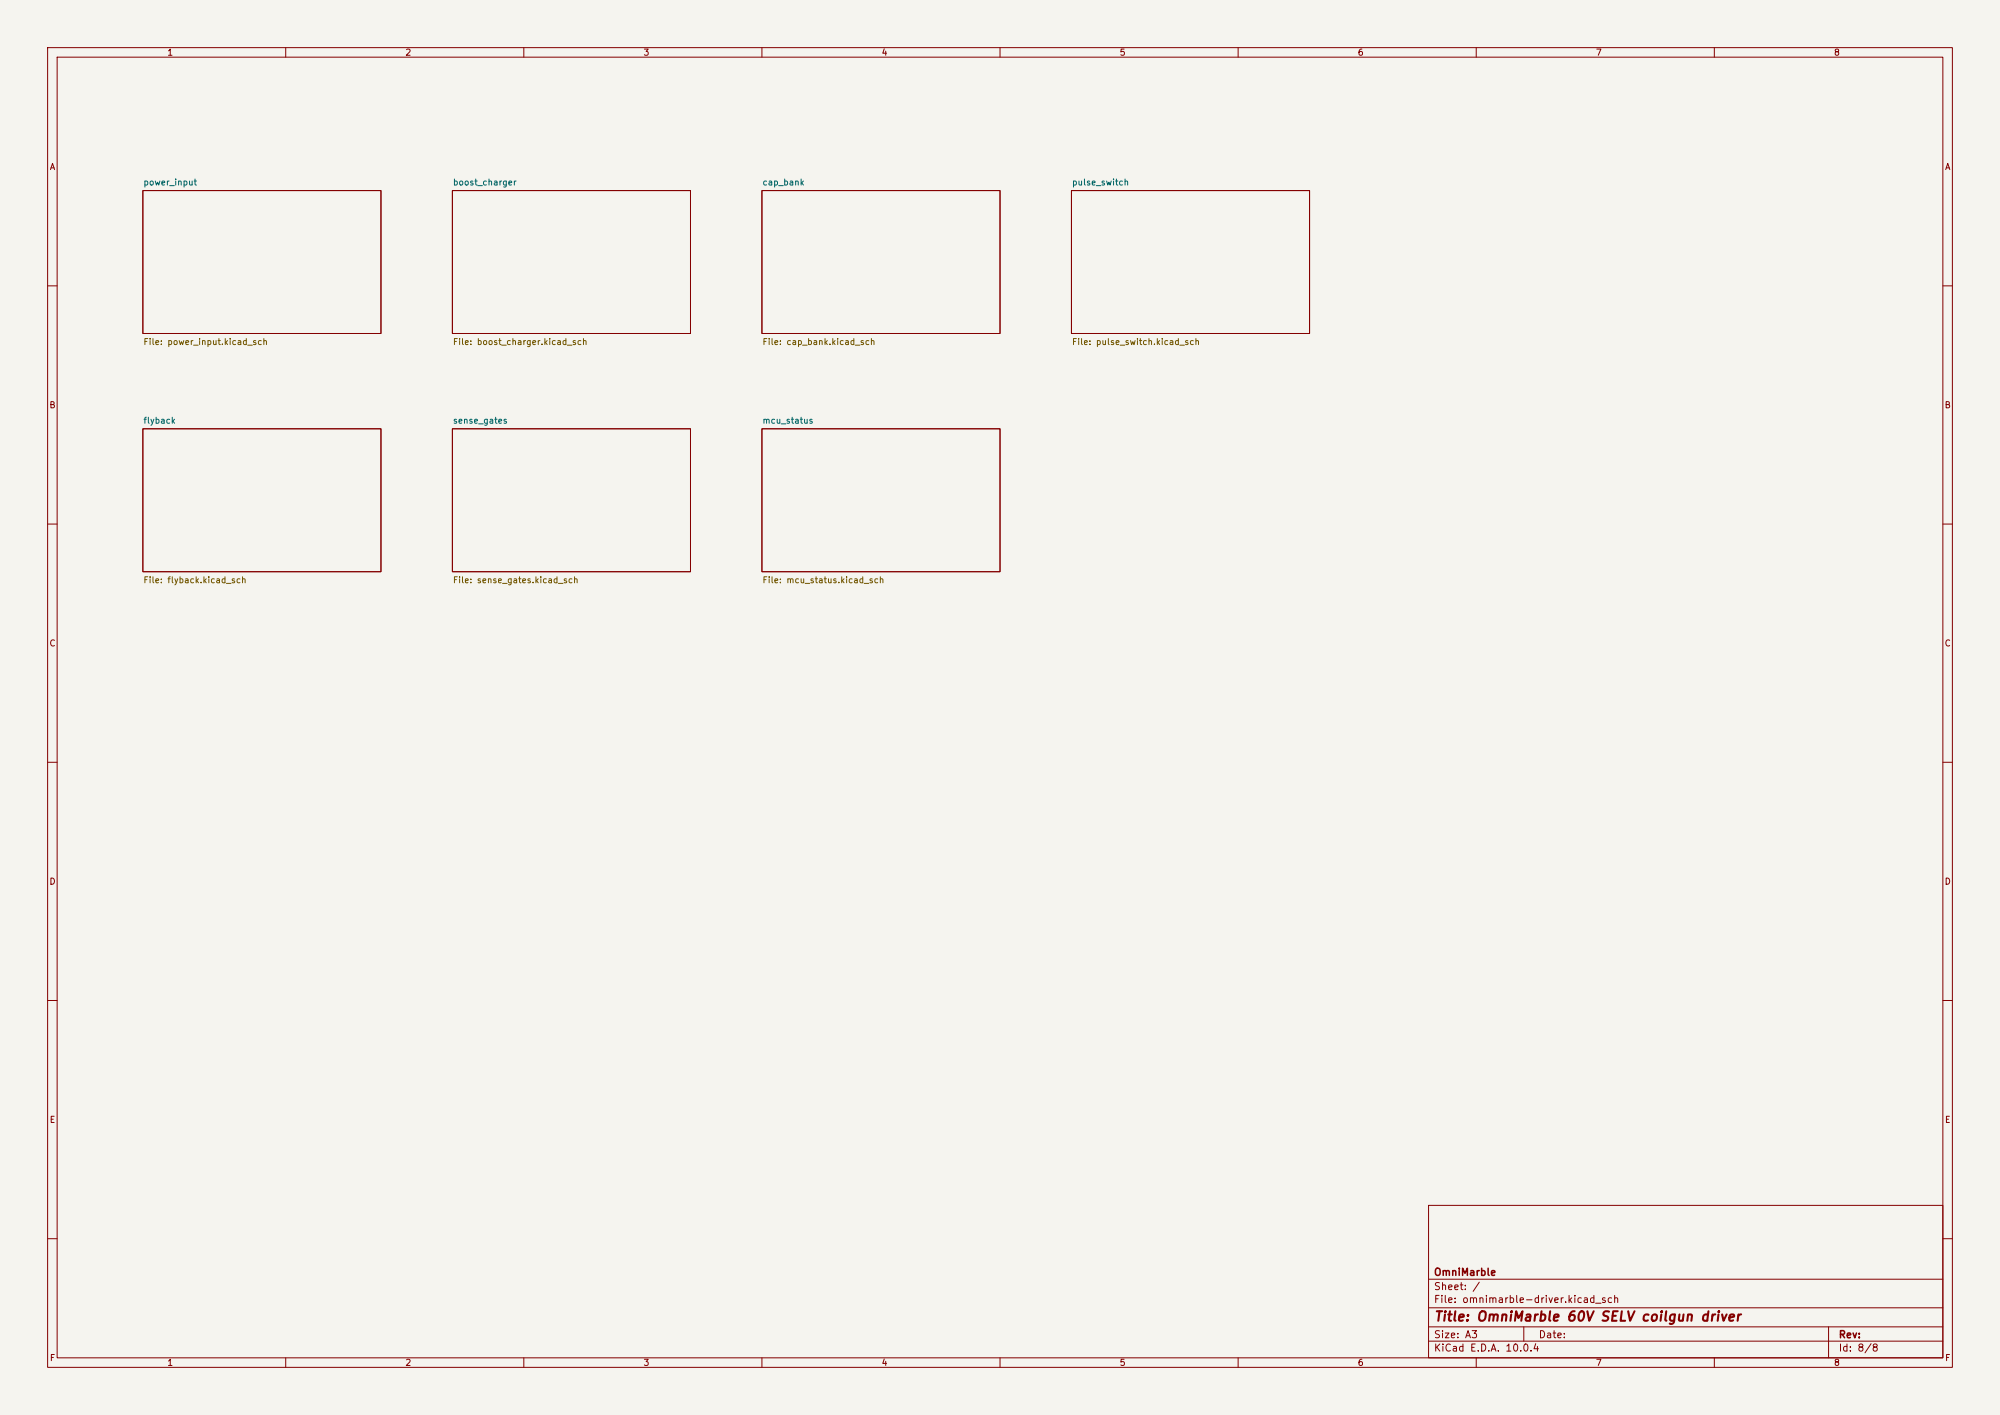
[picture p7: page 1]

OmniMarble
Sheet: /
File: omnimarble-driver.kicad_sch
Title: OmniMarble 60V SELV coilgun driver

Size: A3 | Rev:
KiCad E.D.A. 10.0.4 | Id: 8/8 | F Date:

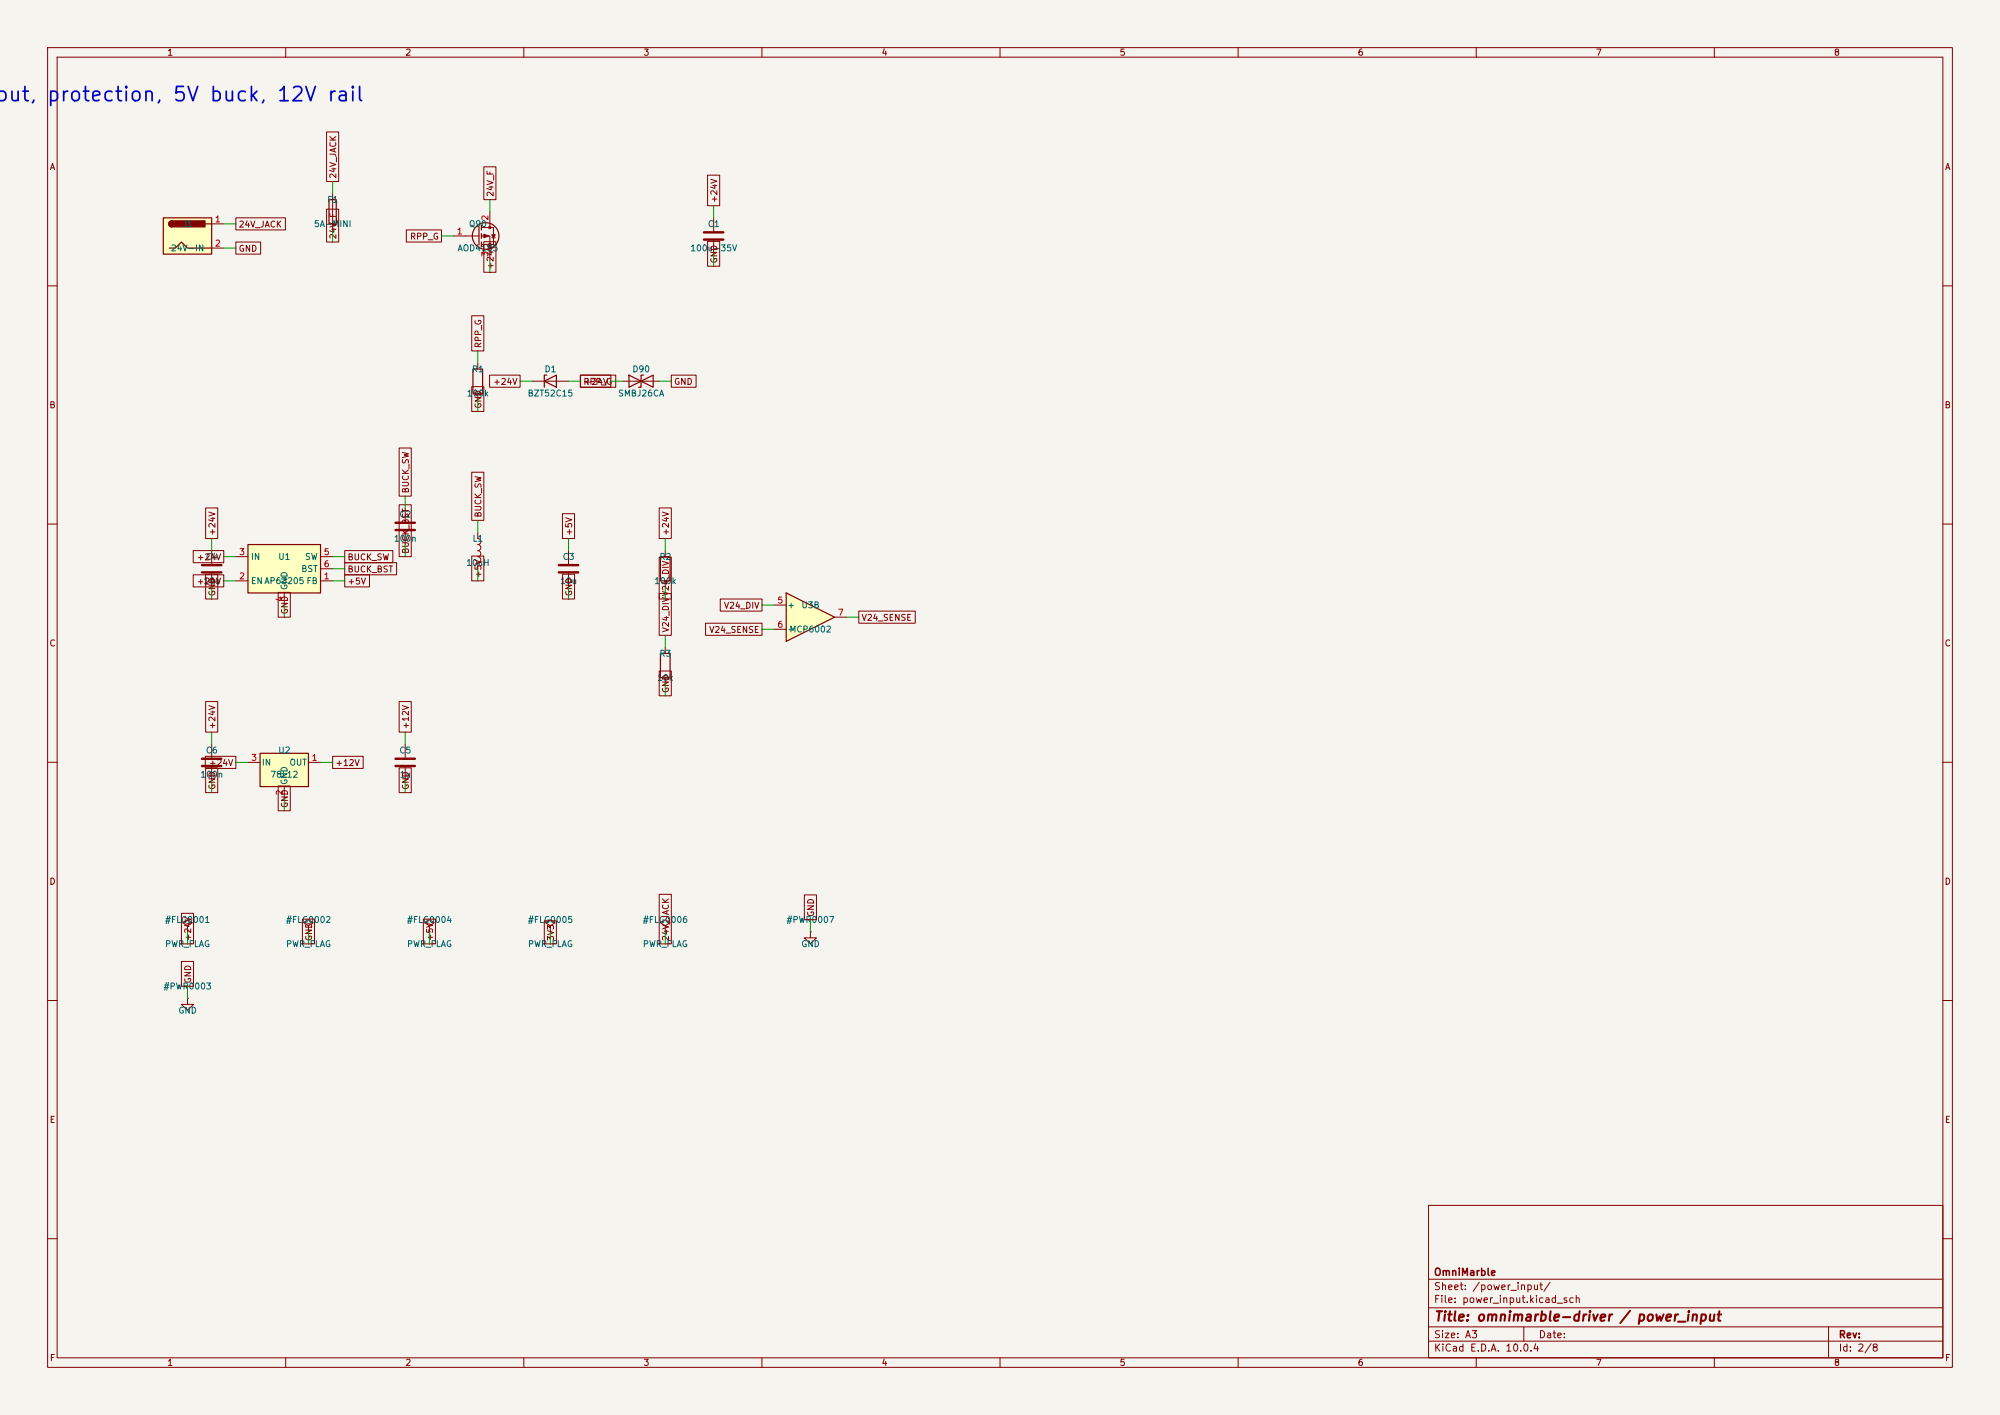
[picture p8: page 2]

BUCK_BST +5V +24V 24V input, protection, 5V buck, 12V rail

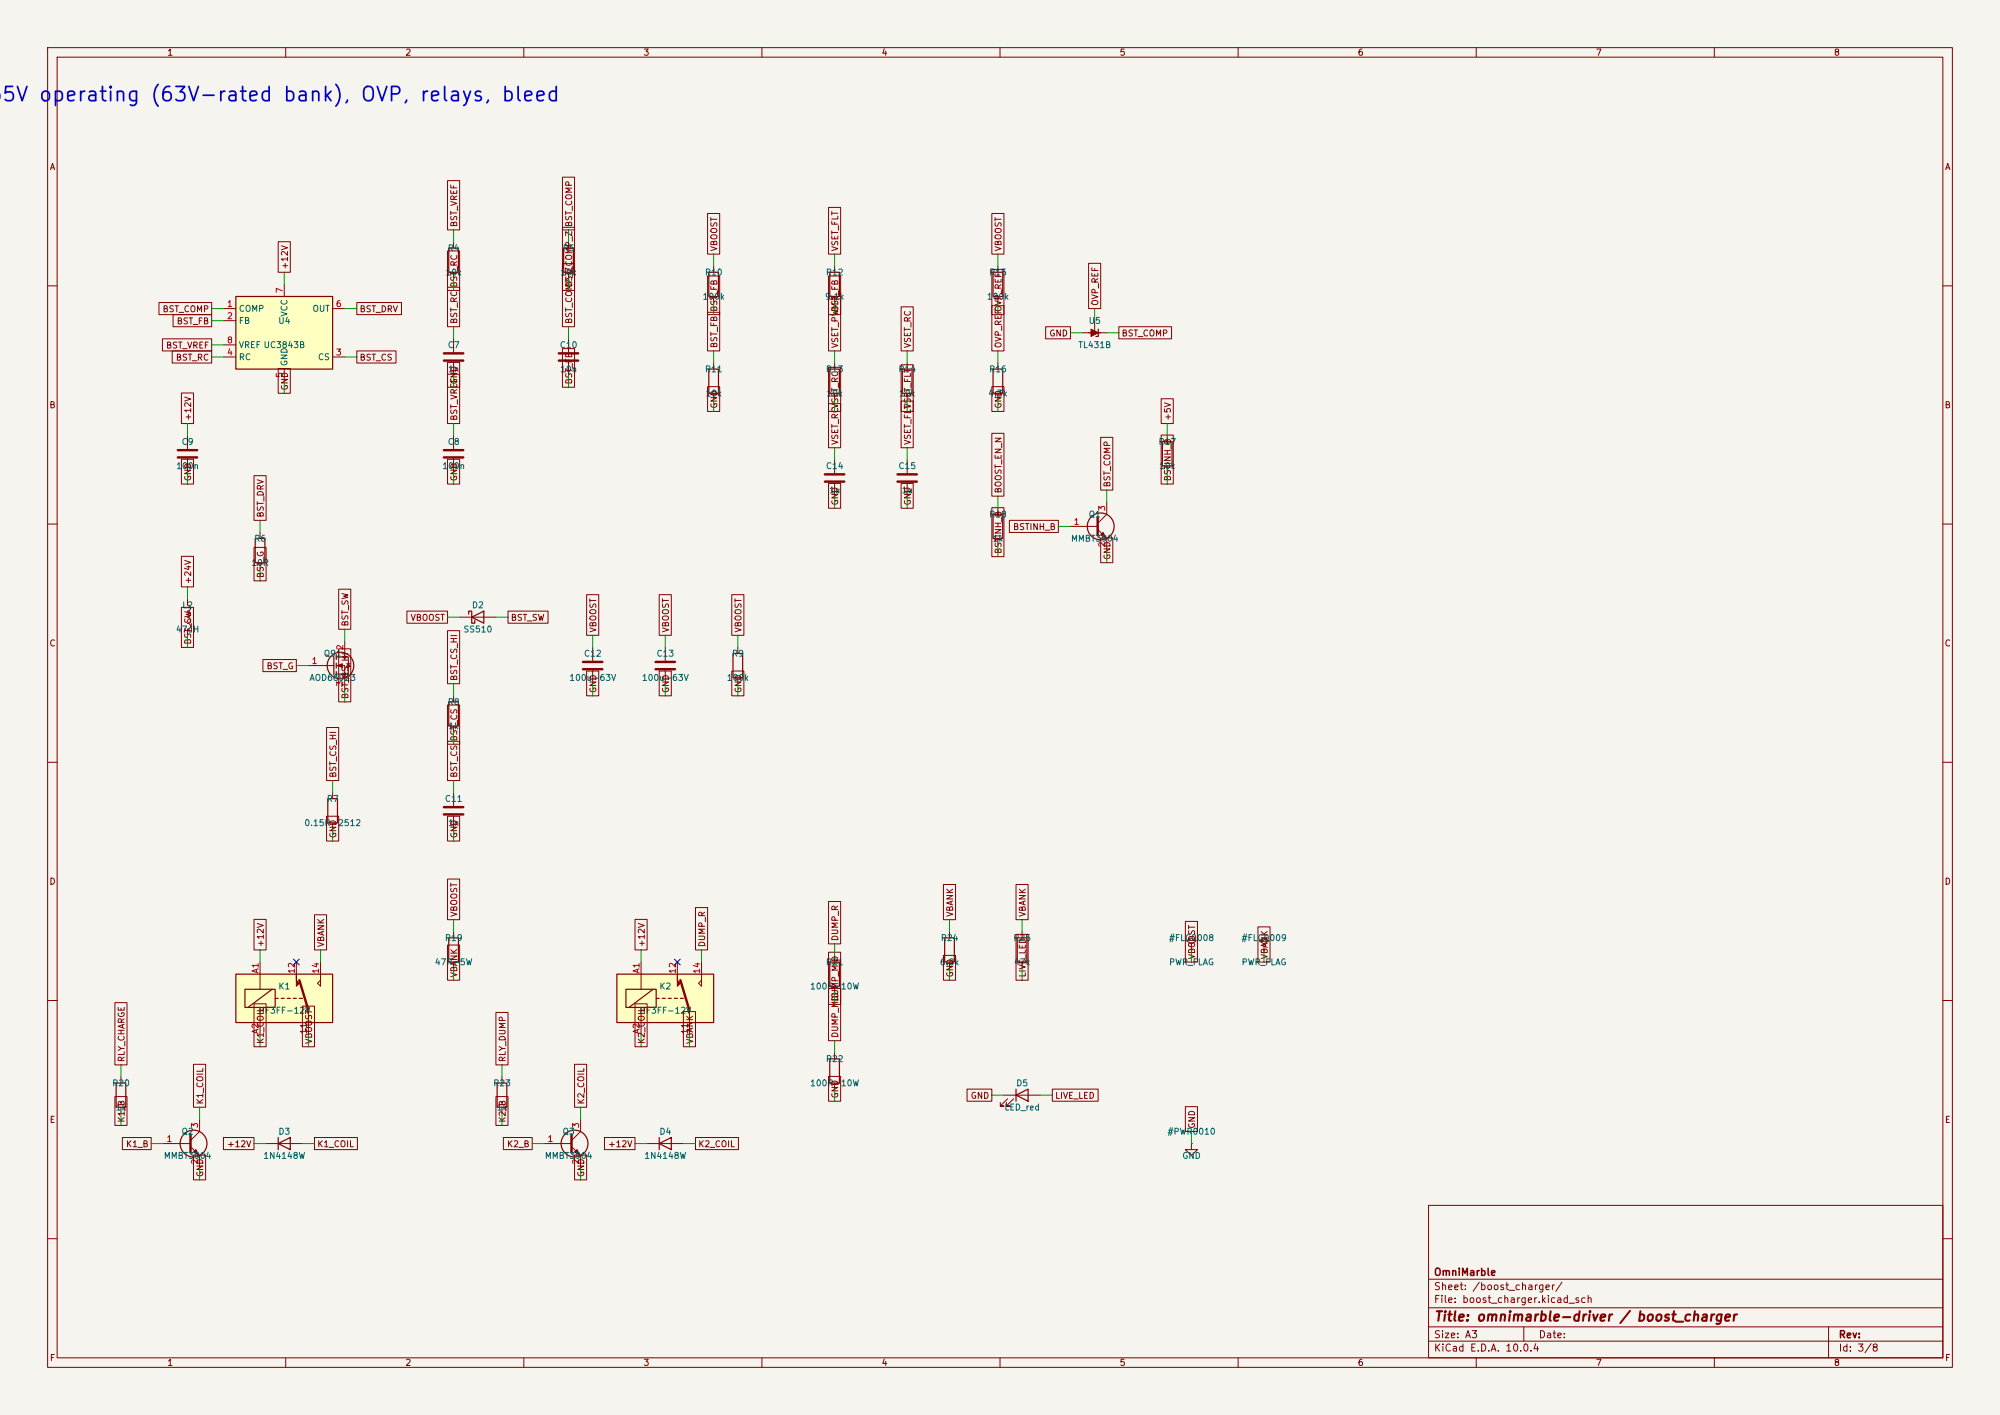
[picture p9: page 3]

Boost charger 24V -> 55V operating (63V-rated bank), OVP, relays, bleed

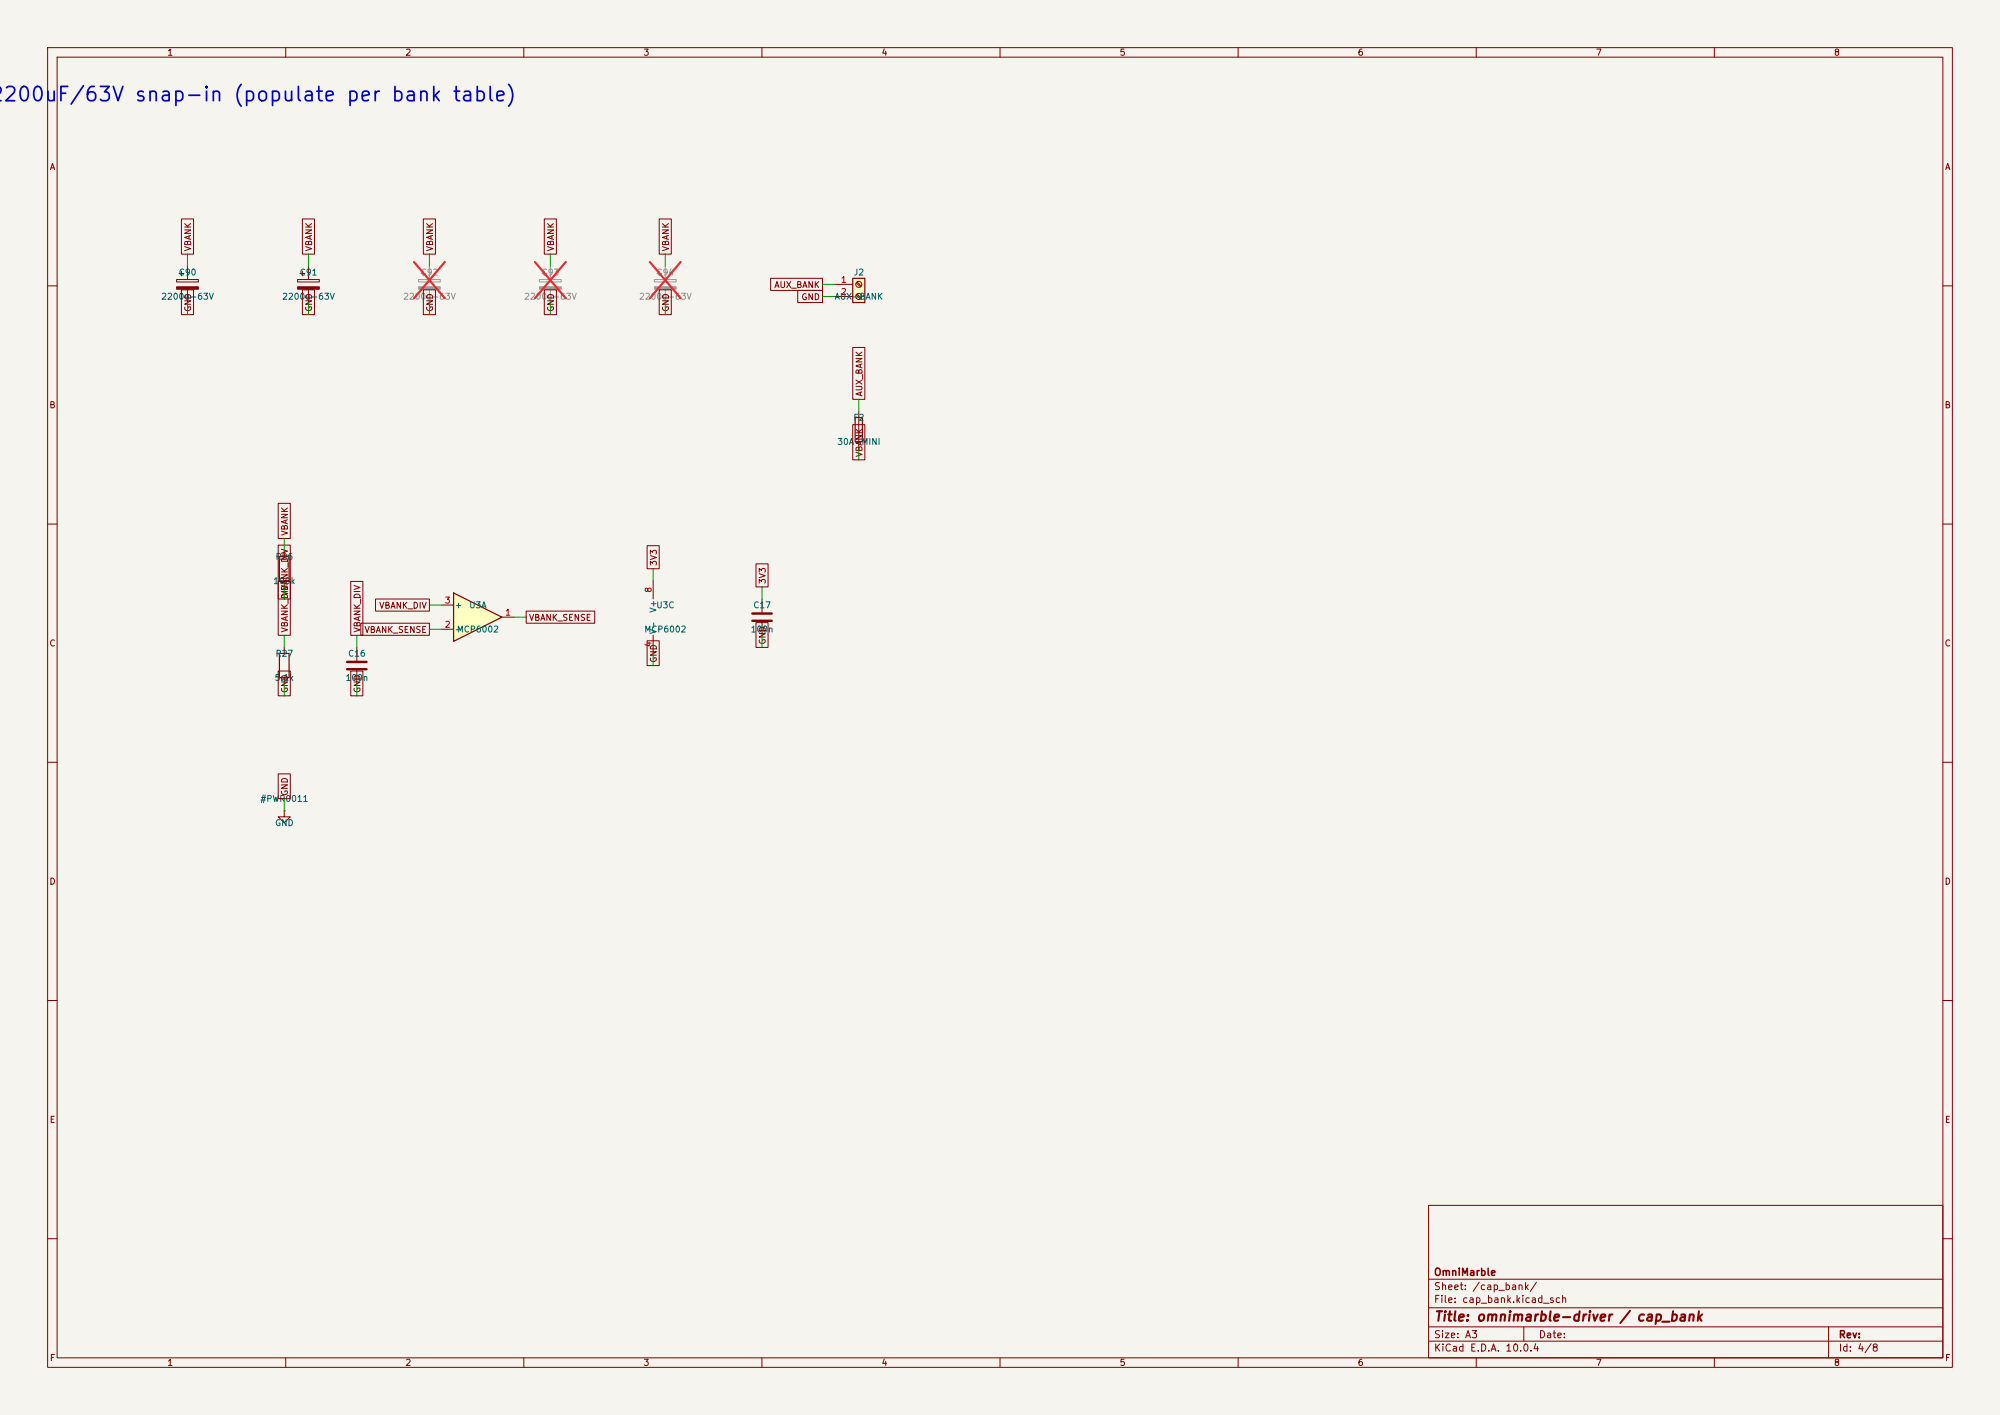
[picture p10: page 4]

Capacitor bank: 5x 2200uF/63V snap-in (populate per bank table)

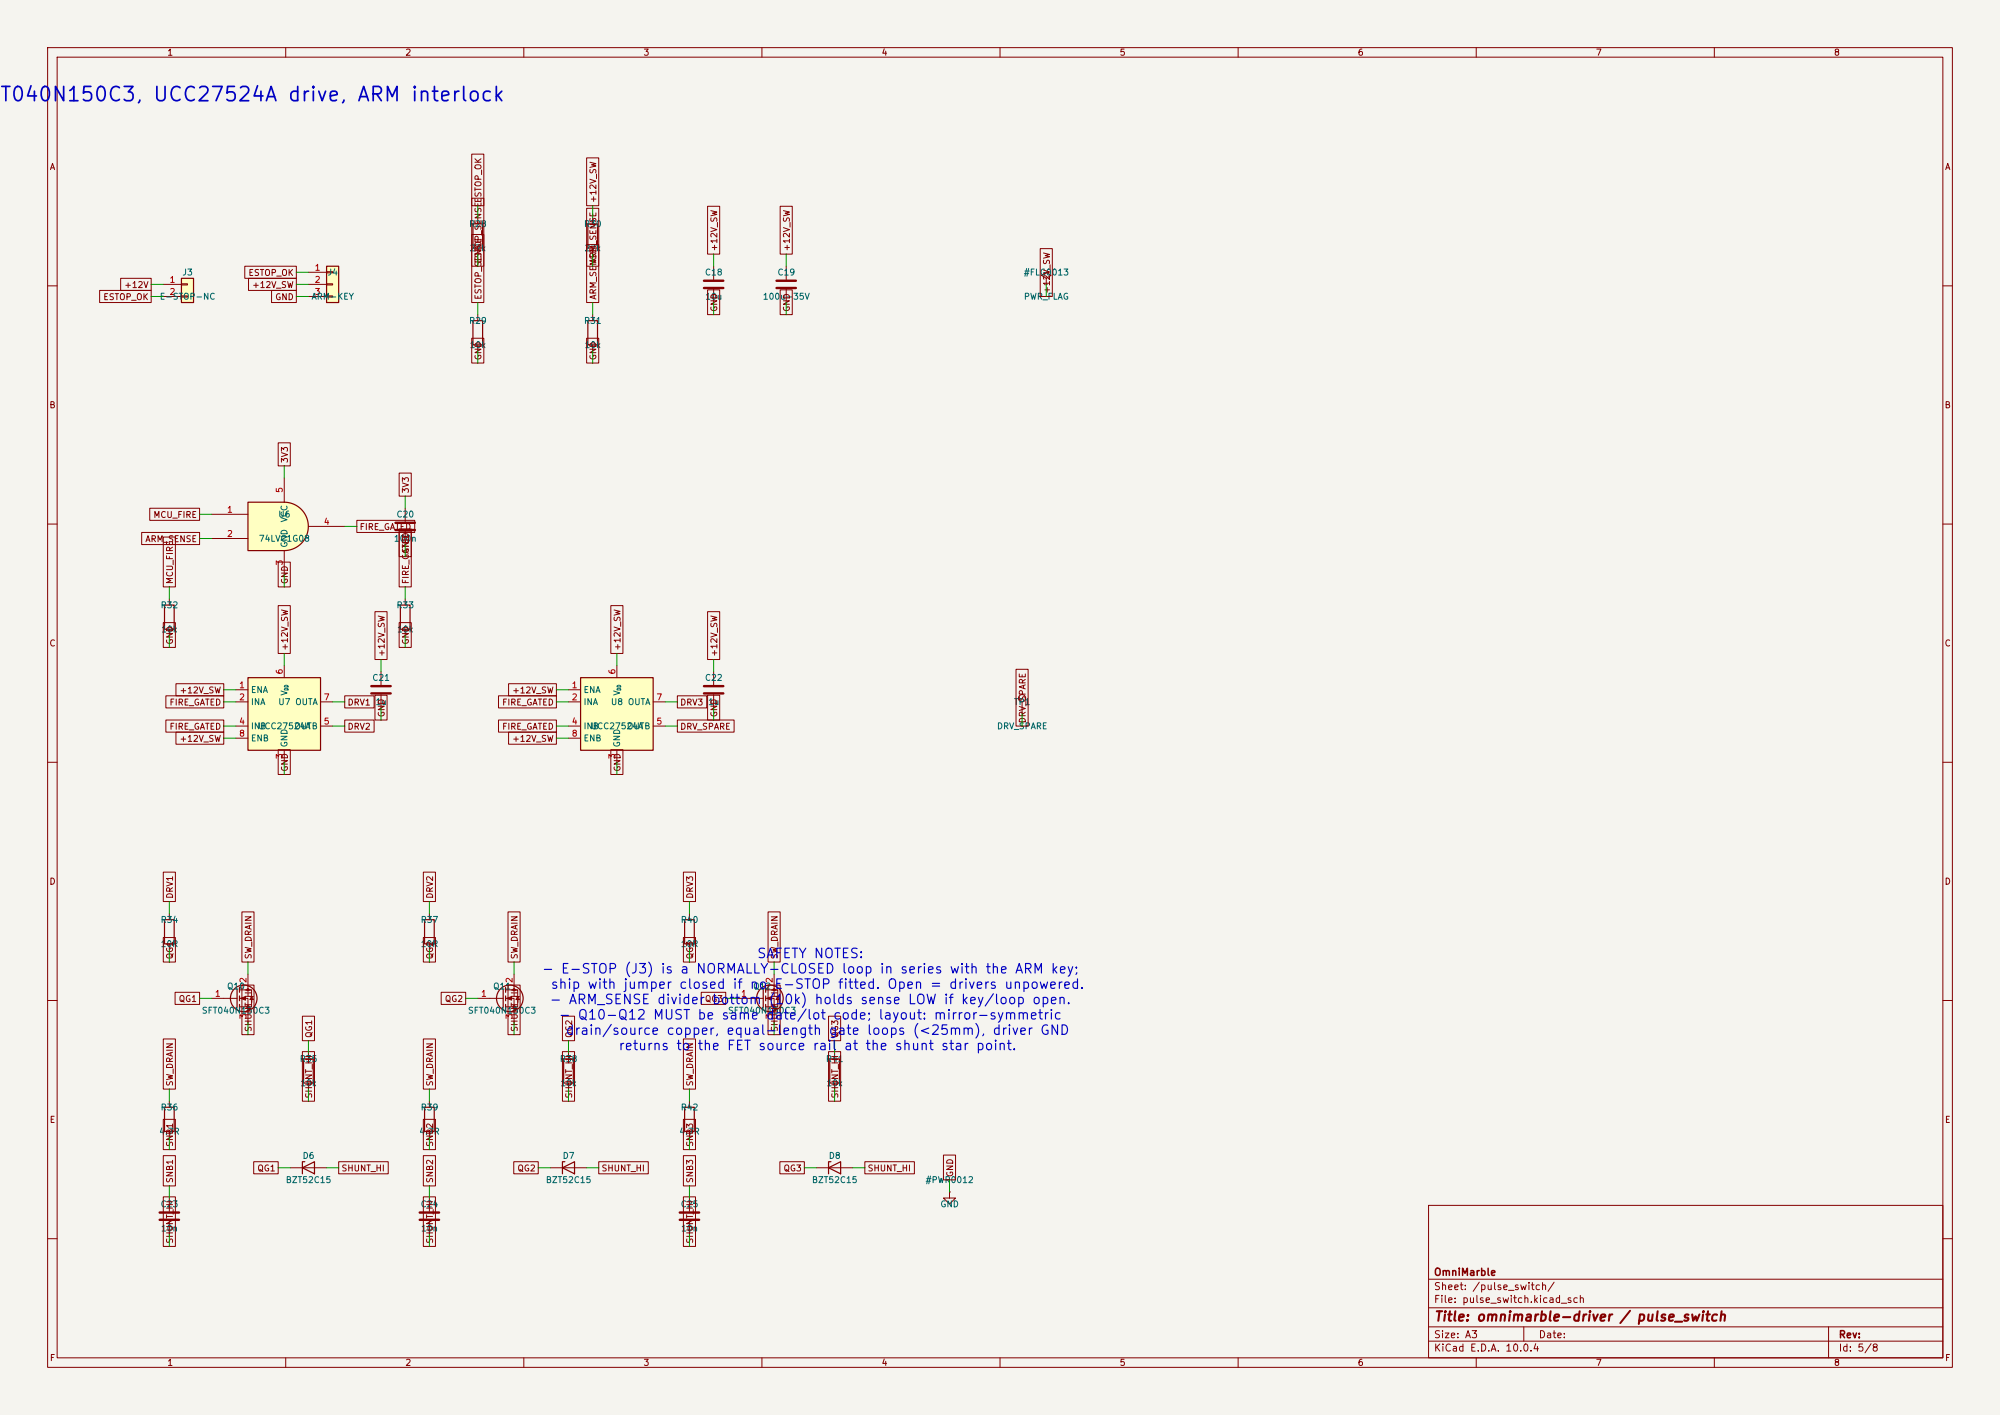
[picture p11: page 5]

Pulse switch: 3x SFT040N150C3, UCC27524A drive, ARM interlock

SAFETY NOTES: - E-STOP (J3) is a NORMALLY-CLOSED loop in series with the ARM key;

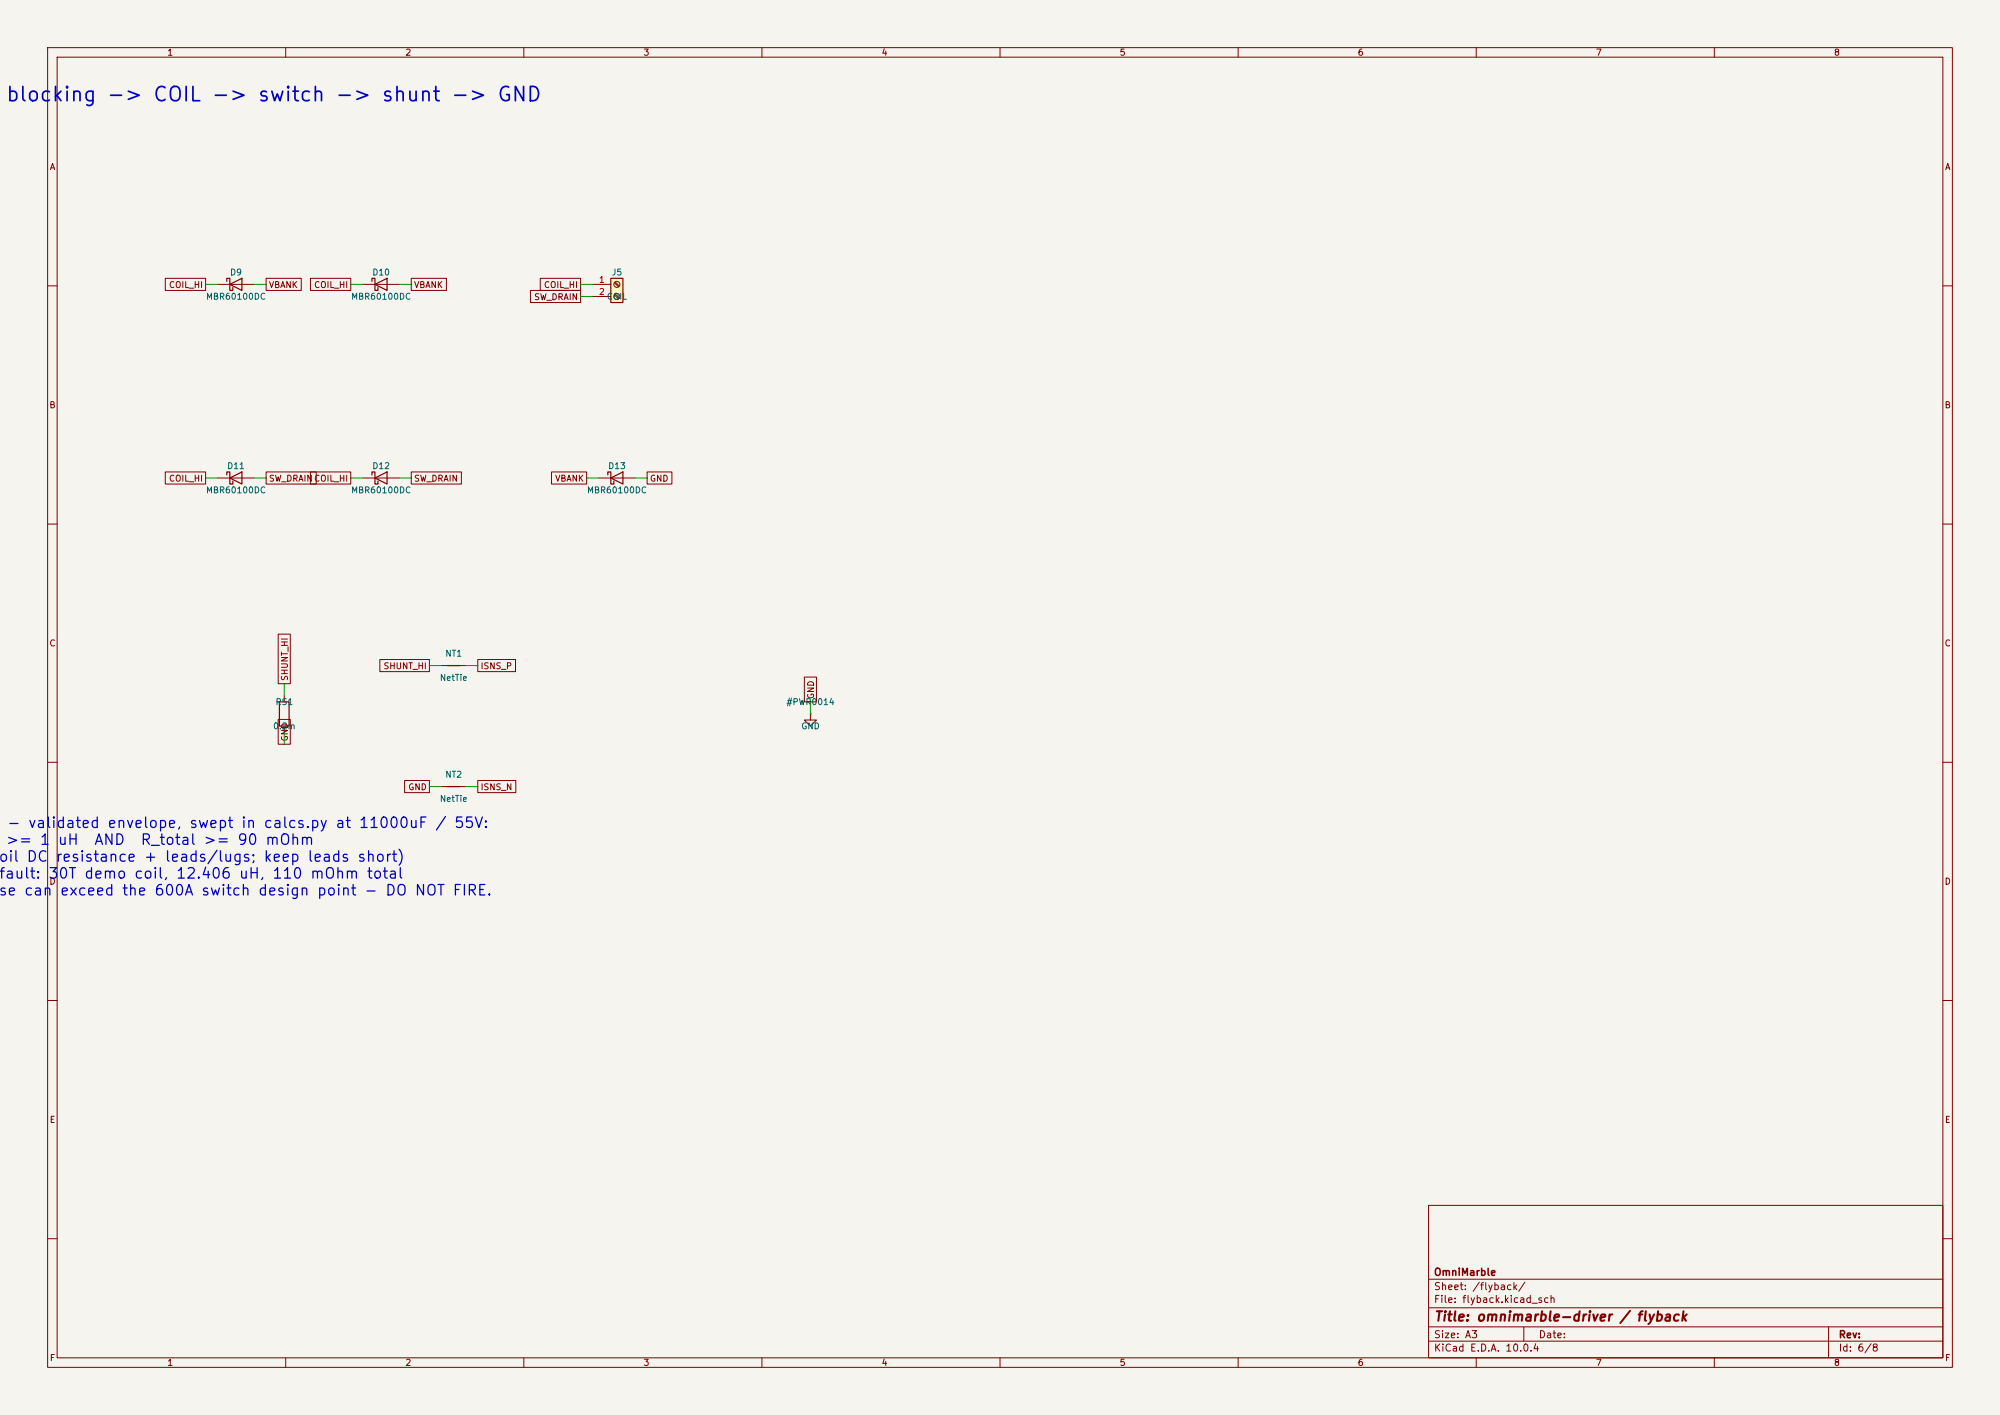
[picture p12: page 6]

Pulse loop: VBANK -> blocking -> COIL -> switch -> shunt -> GND

SW_DRAIN COIL REQUIREMENTS (J5) - validated envelope, swept in calcs.py at 11000uF / 55V:

(R_total = coil DC resistance + leads/lugs; keep leads short)
Validated default: 30T demo coil, 12.406 uH, 110 mOhm total

Below envelope the pulse can exceed the 600A switch design point - DO NOT FIRE.

OmniMarble
Sheet: /flyback/
File: flyback.kicad_sch
Title: omnimarble-driver / flyback

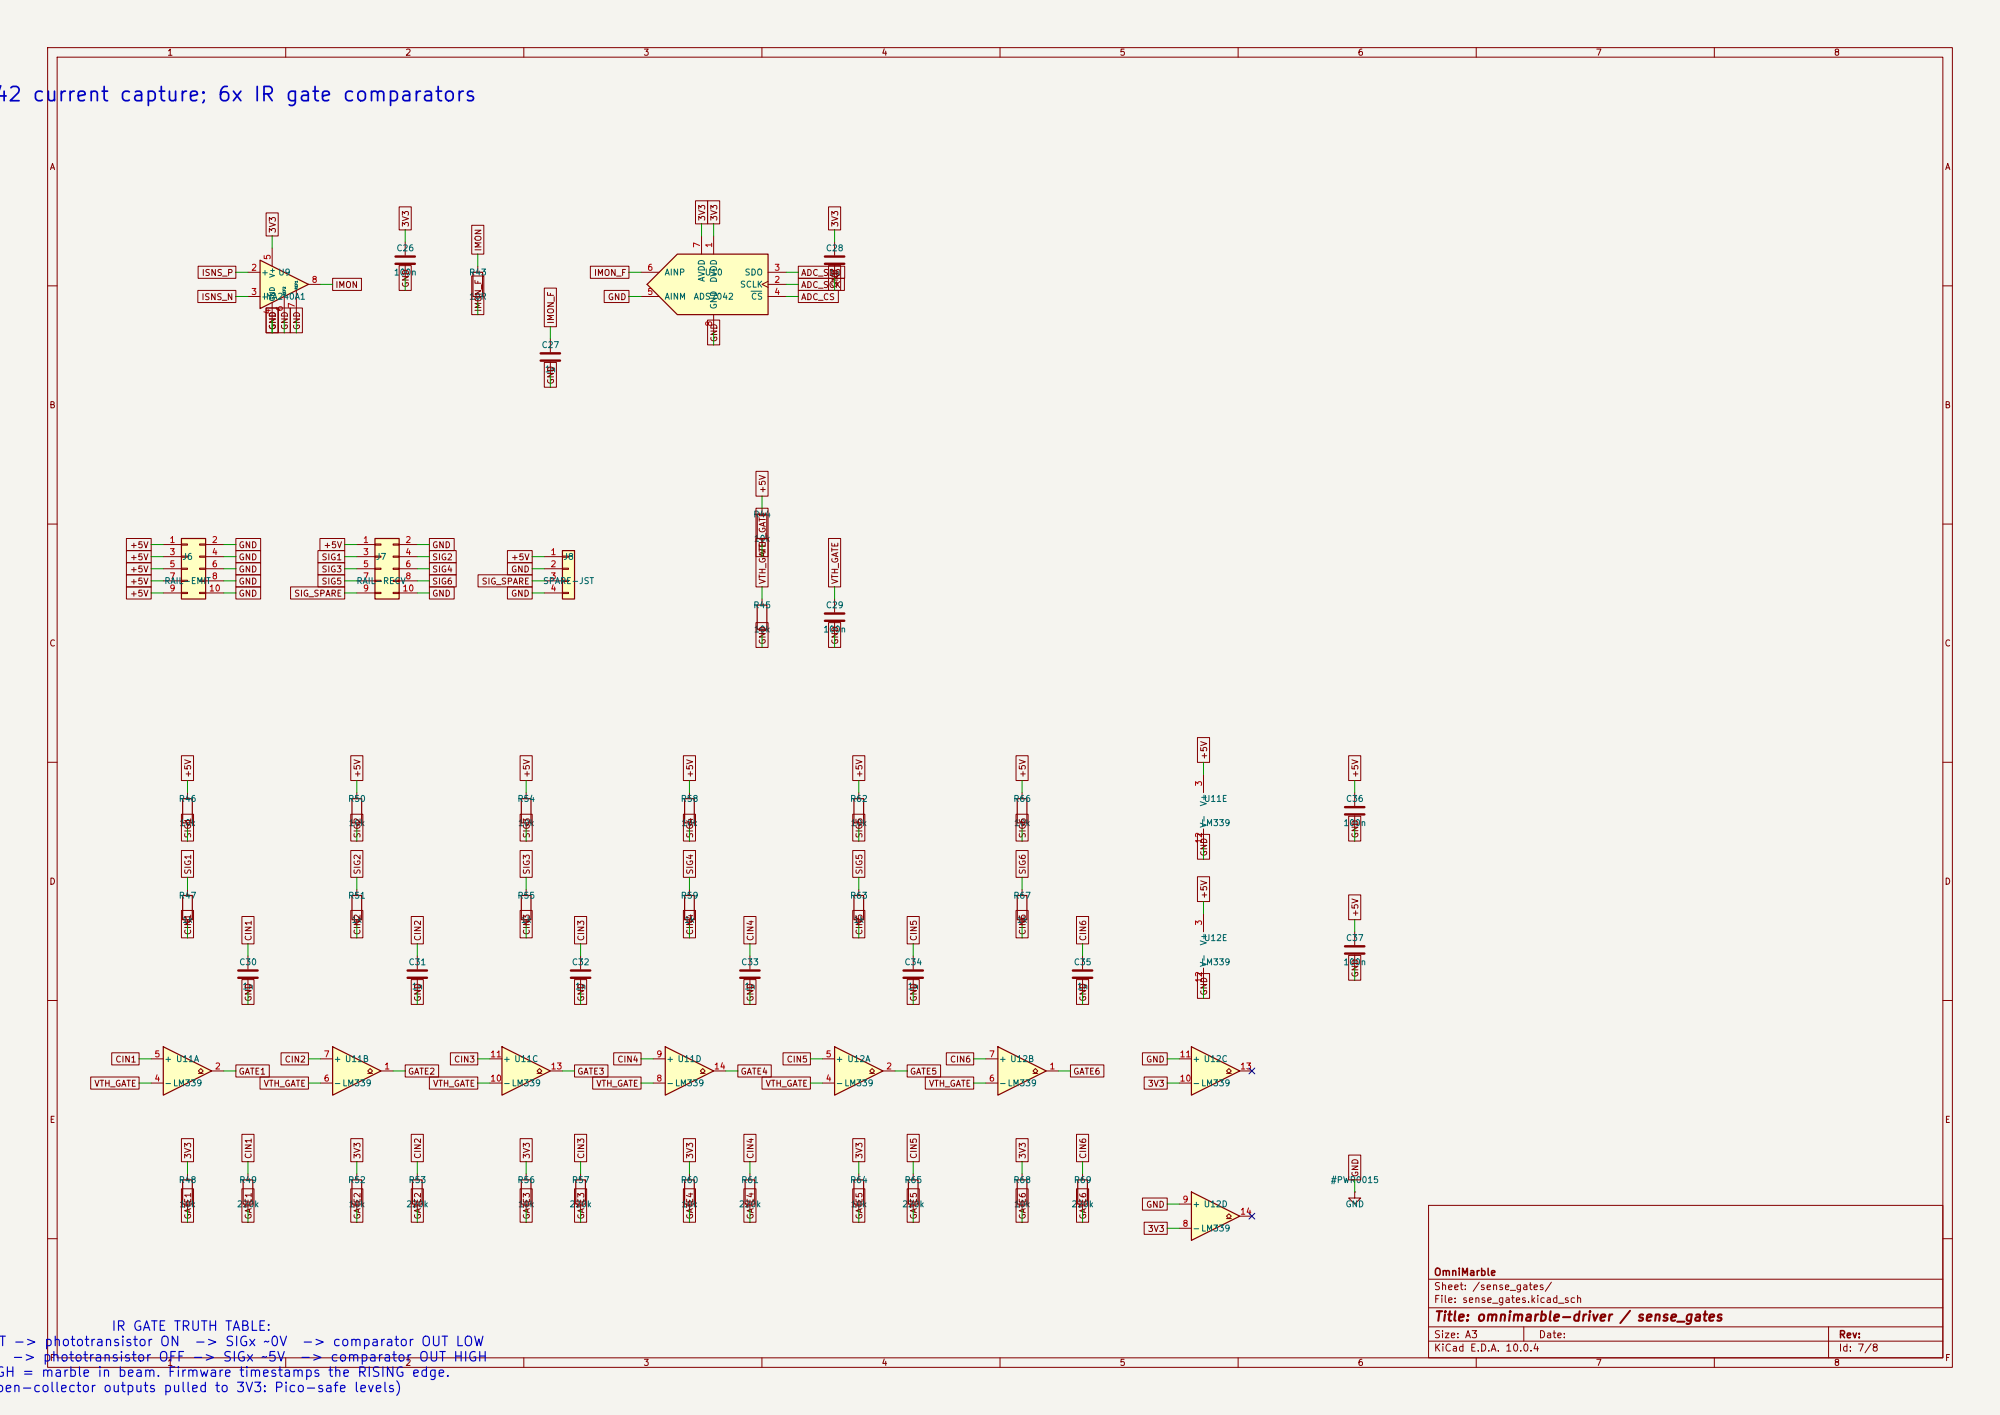
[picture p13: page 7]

INA240 + ADS7042 current capture; 6x IR gate comparators
ADC_SDOGND 3V3 GND VTH_GATEVTH_GATE +5V GND
10k DVDD
IMON

IR GATE TRUTH TABLE:

beam PRESENT -> phototransistor ON -> SIGx ~0V -> comparator OUT LOW

GATEx HIGH = marble in beam. Firmware timestamps the RISING edge.

(open-collector outputs pulled to 3V3: Pico-safe levels)

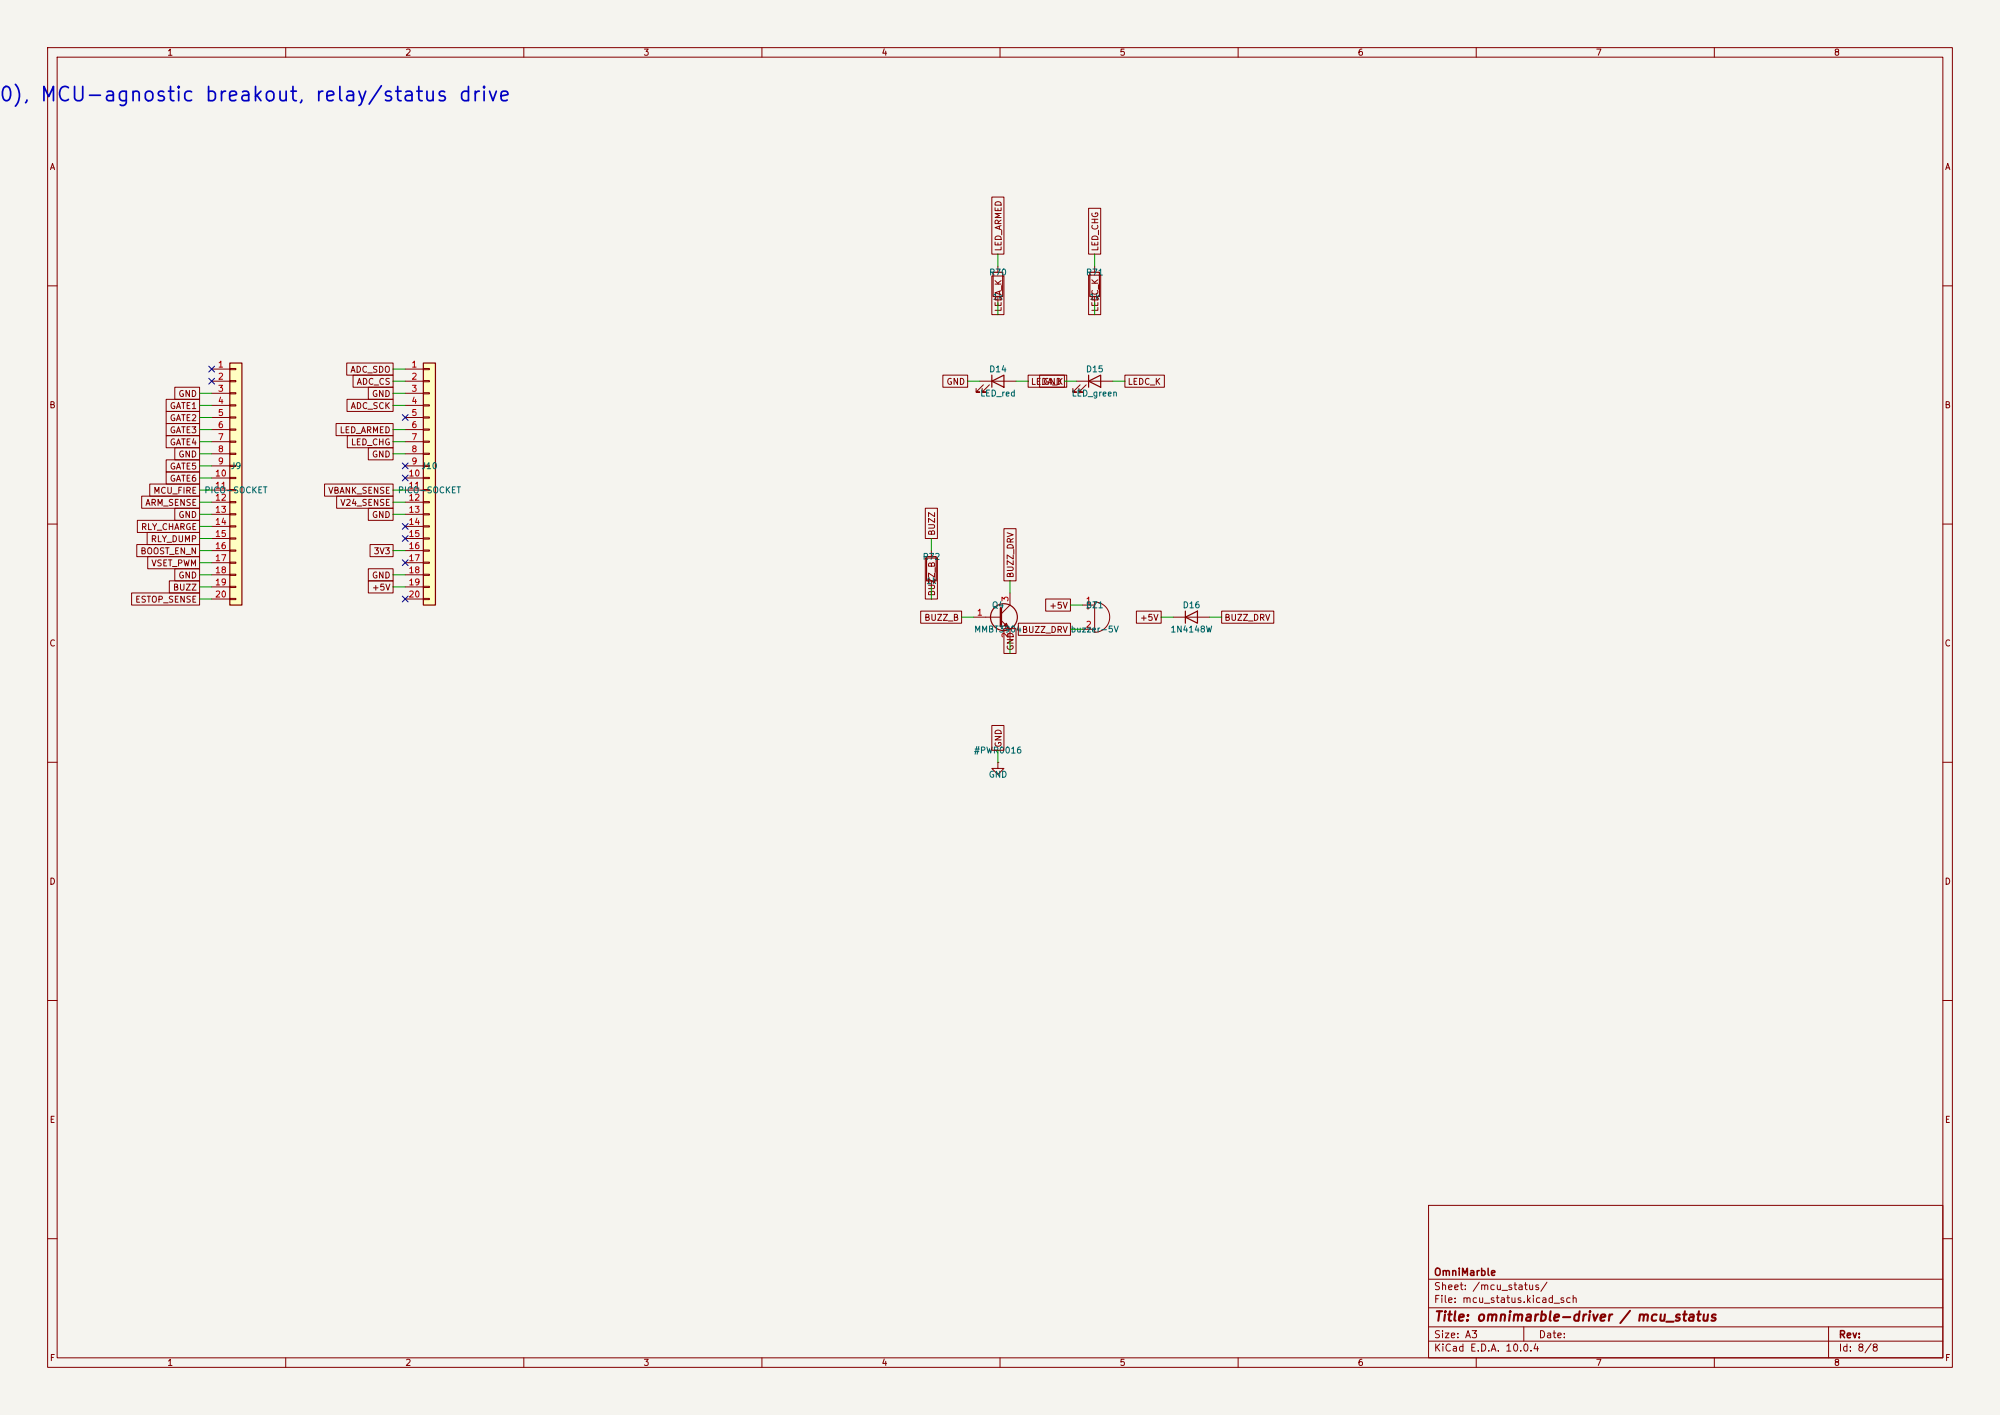
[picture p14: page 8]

Pico socket (2x 1x20), MCU-agnostic breakout, relay/status drive

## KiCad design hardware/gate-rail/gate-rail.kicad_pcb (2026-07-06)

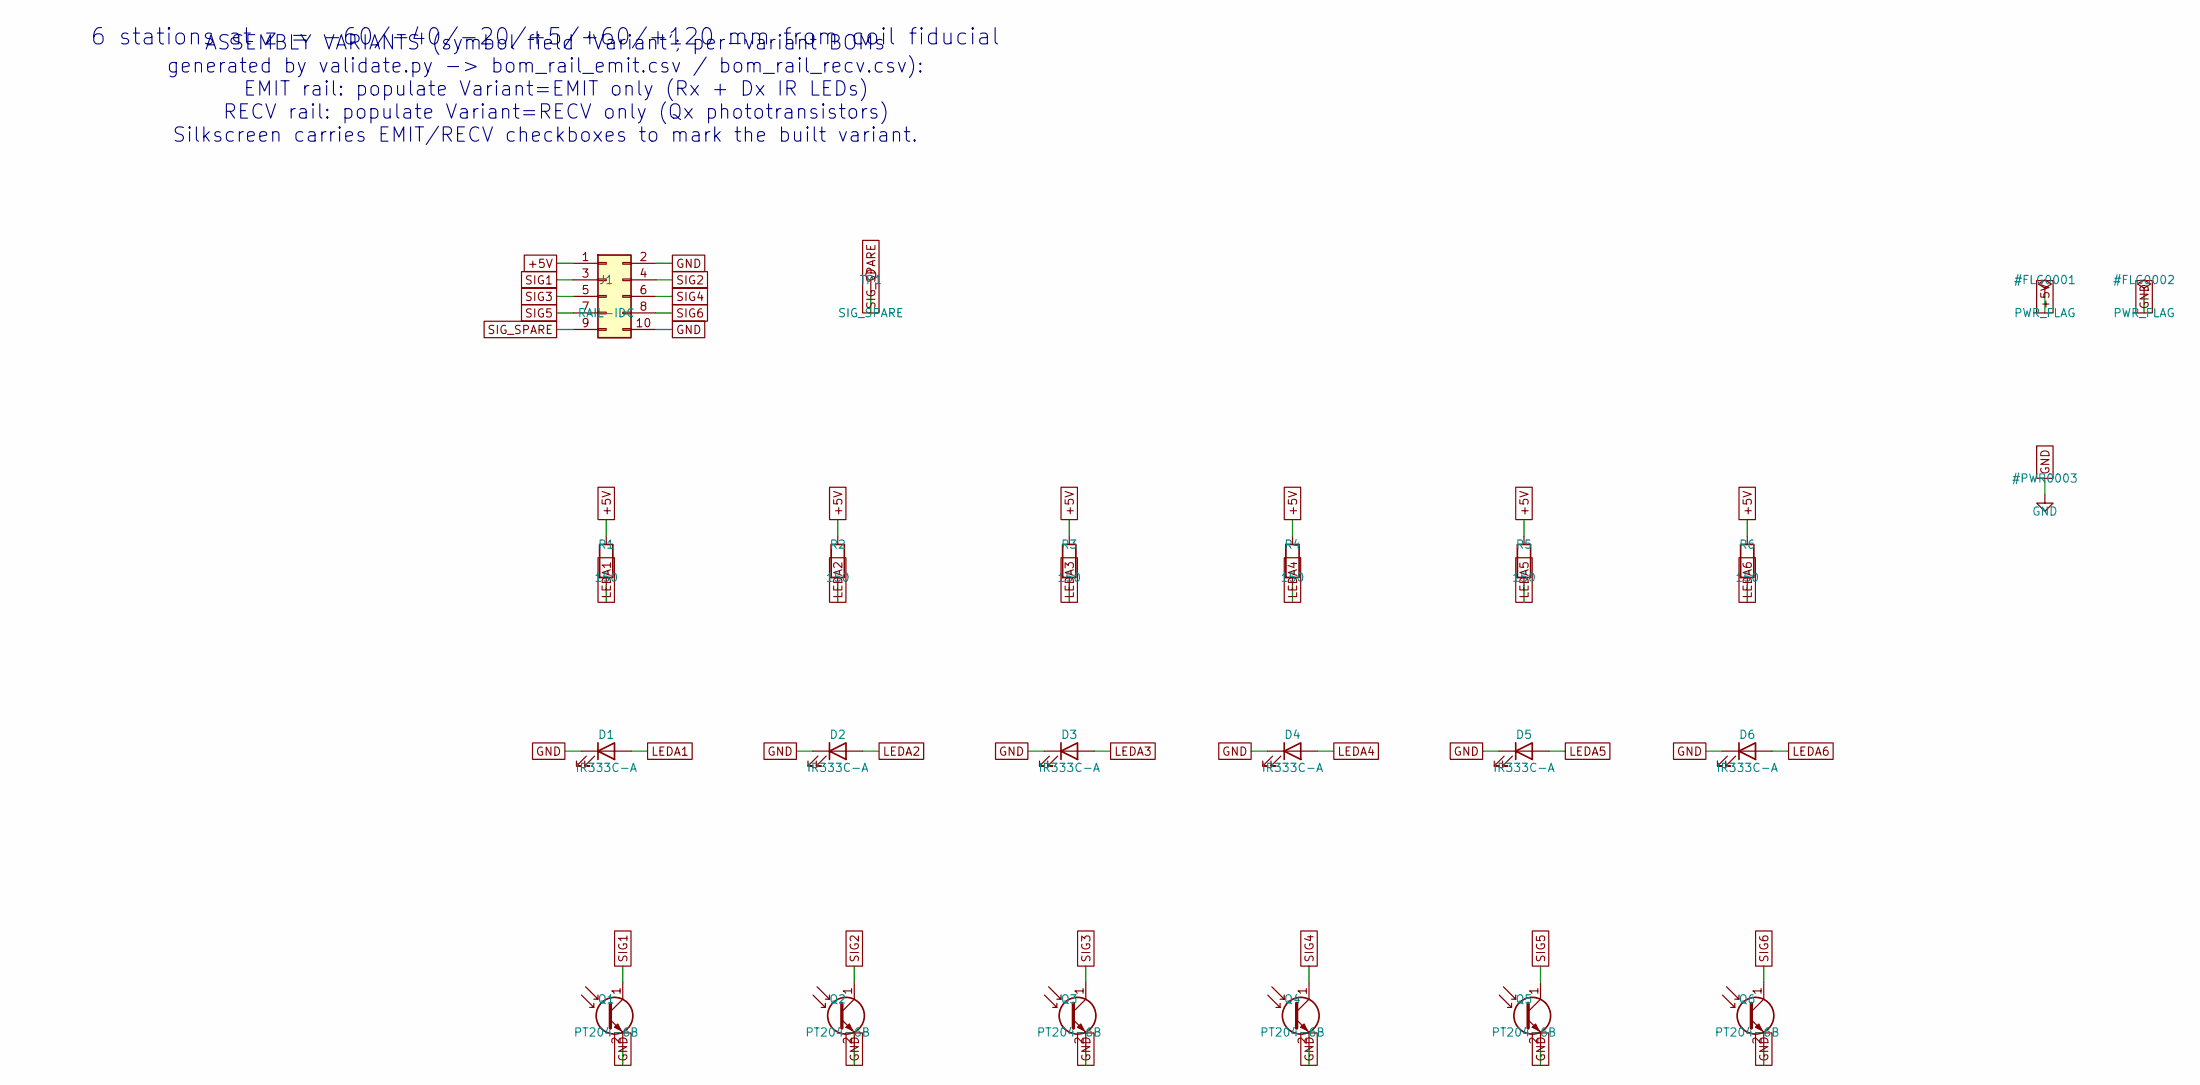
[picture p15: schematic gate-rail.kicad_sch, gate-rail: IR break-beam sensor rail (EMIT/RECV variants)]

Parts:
D1, D2, D3, D4, D5, D6: IR333C-A; LED_D5.0mm; LCSC C5130
J1: RAIL-IDC; IDC-Header_2x05_P2.54mm_Vertical; LCSC C5665
Q1, Q2, Q3, Q4, Q5, Q6: PT204-6B; LED_D3.0mm; LCSC C5133
R1, R2, R3, R4, R5, R6: 150; R_0603_1608Metric; LCSC C22808
TP1: SIG_SPARE; TestPoint_Pad_1.5x1.5mm

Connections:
+5V: J1.1, R1.1, R2.1, R3.1, R4.1, R5.1, R6.1
GND: D1.1 (K), D2.1 (K), D3.1 (K), D4.1 (K), D5.1 (K), D6.1 (K), J1.2, J1.10, Q1.2 (E), Q2.2 (E), Q3.2 (E), Q4.2 (E), Q5.2 (E), Q6.2 (E)
LEDA1: D1.2 (A), R1.2
LEDA2: D2.2 (A), R2.2
LEDA3: D3.2 (A), R3.2
LEDA4: D4.2 (A), R4.2
LEDA5: D5.2 (A), R5.2
LEDA6: D6.2 (A), R6.2
SIG1: J1.3, Q1.1 (C)
SIG2: J1.4, Q2.1 (C)
SIG3: J1.5, Q3.1 (C)
SIG4: J1.6, Q4.1 (C)
SIG5: J1.7, Q5.1 (C)
SIG6: J1.8, Q6.1 (C)
SIG_SPARE: J1.9, TP1.1

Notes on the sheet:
6 stations at z = -60/-40/-20/+5/+60/+120 mm from coil fiducial
ASSEMBLY VARIANTS (symbol field 'Variant'; per-variant BOMs generated by validate.py -> bom_rail_emit.csv / bom_rail_recv.csv): EMIT rail: populate Variant=EMIT only (Rx + Dx IR LEDs) RECV rail: populate Variant=RECV only (Qx phototransistors) Silkscreen carries EMIT/RECV checkboxes to mark the bui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

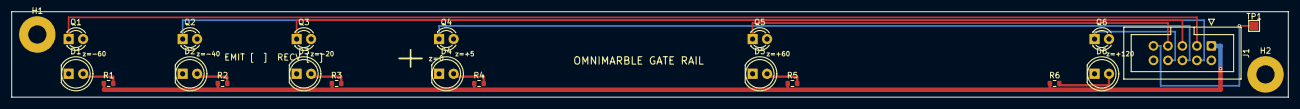
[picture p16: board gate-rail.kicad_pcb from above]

Board: 2 copper layers, 224.0 x 15.0 mm, 22 parts (0 on the bottom side), 15 nets.

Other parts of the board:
H1, H2: MountingHole_3.2mm_M3_Pad

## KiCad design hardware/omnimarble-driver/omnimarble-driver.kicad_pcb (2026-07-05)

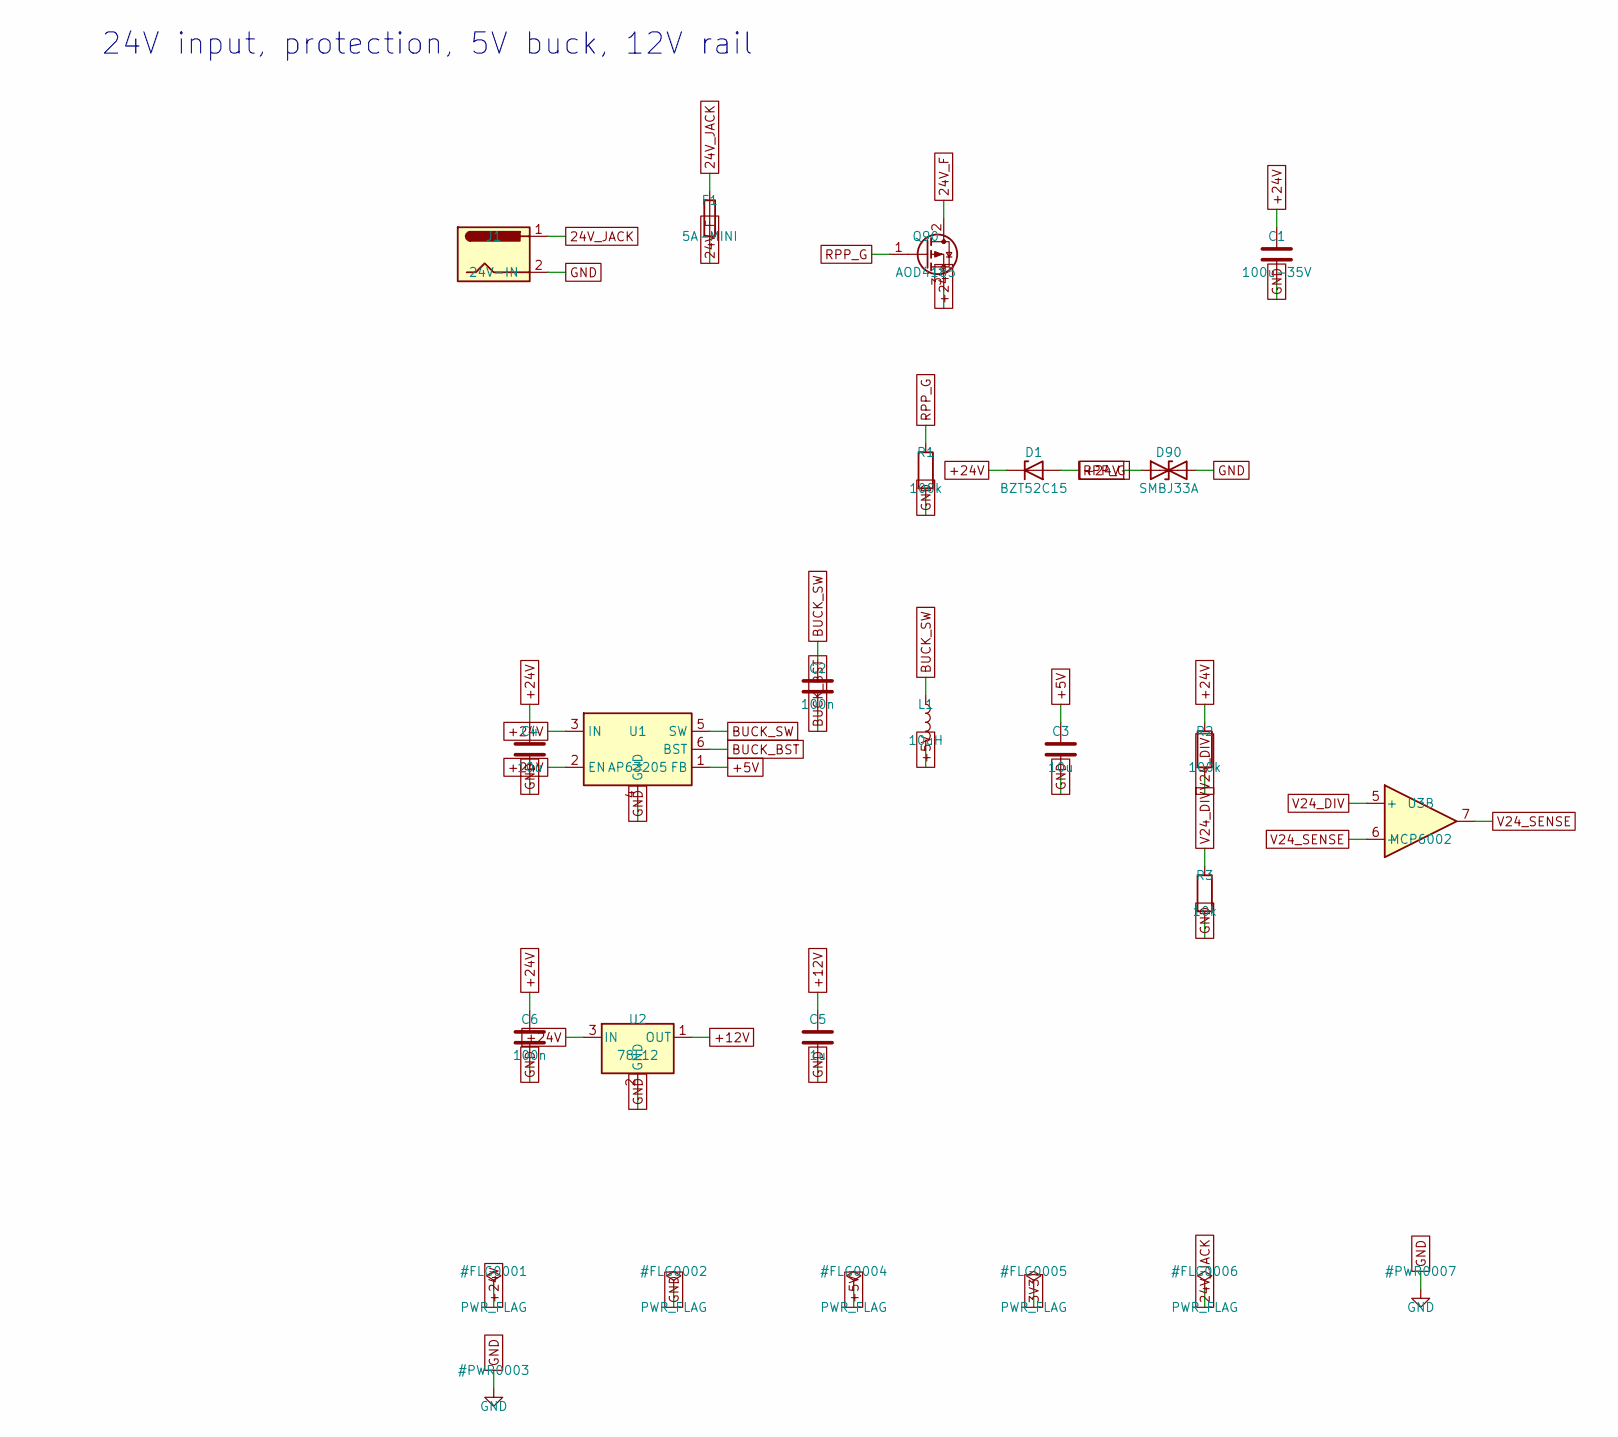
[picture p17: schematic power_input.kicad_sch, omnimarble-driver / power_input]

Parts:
C1: 100u-35V; CP_Elec_6.3x7.7; LCSC C176666
C2, C6: 100n; C_0603_1608Metric; LCSC C14663
C3, C4: 10u; C_0805_2012Metric; LCSC C15850
C5: 1u; C_0603_1608Metric; LCSC C15849
D1: BZT52C15; D_SOD-123; LCSC C19077412
D90: SMBJ33A; D_SMB; LCSC C19077586
F1: 5A-MINI; Fuseholder_Blade_Mini_Keystone_3568; LCSC C5249699
J1: 24V-IN; BarrelJack_Horizontal; LCSC C381116
L1: 10uH; L_Changjiang_FNR6045S; LCSC C79272
Q90: AOD4185; TO-252-2; LCSC C77317
R1, R2: 100k; R_0603_1608Metric; LCSC C25803
R3: 10k; R_0603_1608Metric; LCSC C25804
U1: AP63205; TSOT-23-6; LCSC C2071056
U2: 78L12; SOT-89-3; LCSC C347272
U3: MCP6002; SOIC-8_3.9x4.9mm_P1.27mm; LCSC C7377

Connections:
24V_F: F1.2, Q90.2 (D)
24V_JACK: F1.1, J1.1
+5V: C3.1, L1.2, U1.1 (FB); also elsewhere on the board
+12V: C5.1, U2.1 (OUT); also elsewhere on the board
+24V: C1.1, C4.1, C6.1, D1.1 (K), D90.1 (A1), Q90.3 (S), R2.1, U1.2 (EN), U1.3 (IN), U2.3 (IN); also elsewhere on the board
BUCK_BST: C2.2, U1.6 (BST)
BUCK_SW: C2.1, L1.1, U1.5 (SW)
GND: C1.2, C3.2, C4.2, C5.2, C6.2, D90.2 (A2), J1.2, R1.2, R3.2, U1.4 (GND), U2.2 (GND); also elsewhere on the board
RPP_G: D1.2 (A), Q90.1 (G), R1.1
V24_DIV: R2.2, R3.1, U3.5 (+)
V24_SENSE: U3.6 (-), U3.7; also elsewhere on the board

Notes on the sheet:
24V input, protection, 5V buck, 12V rail

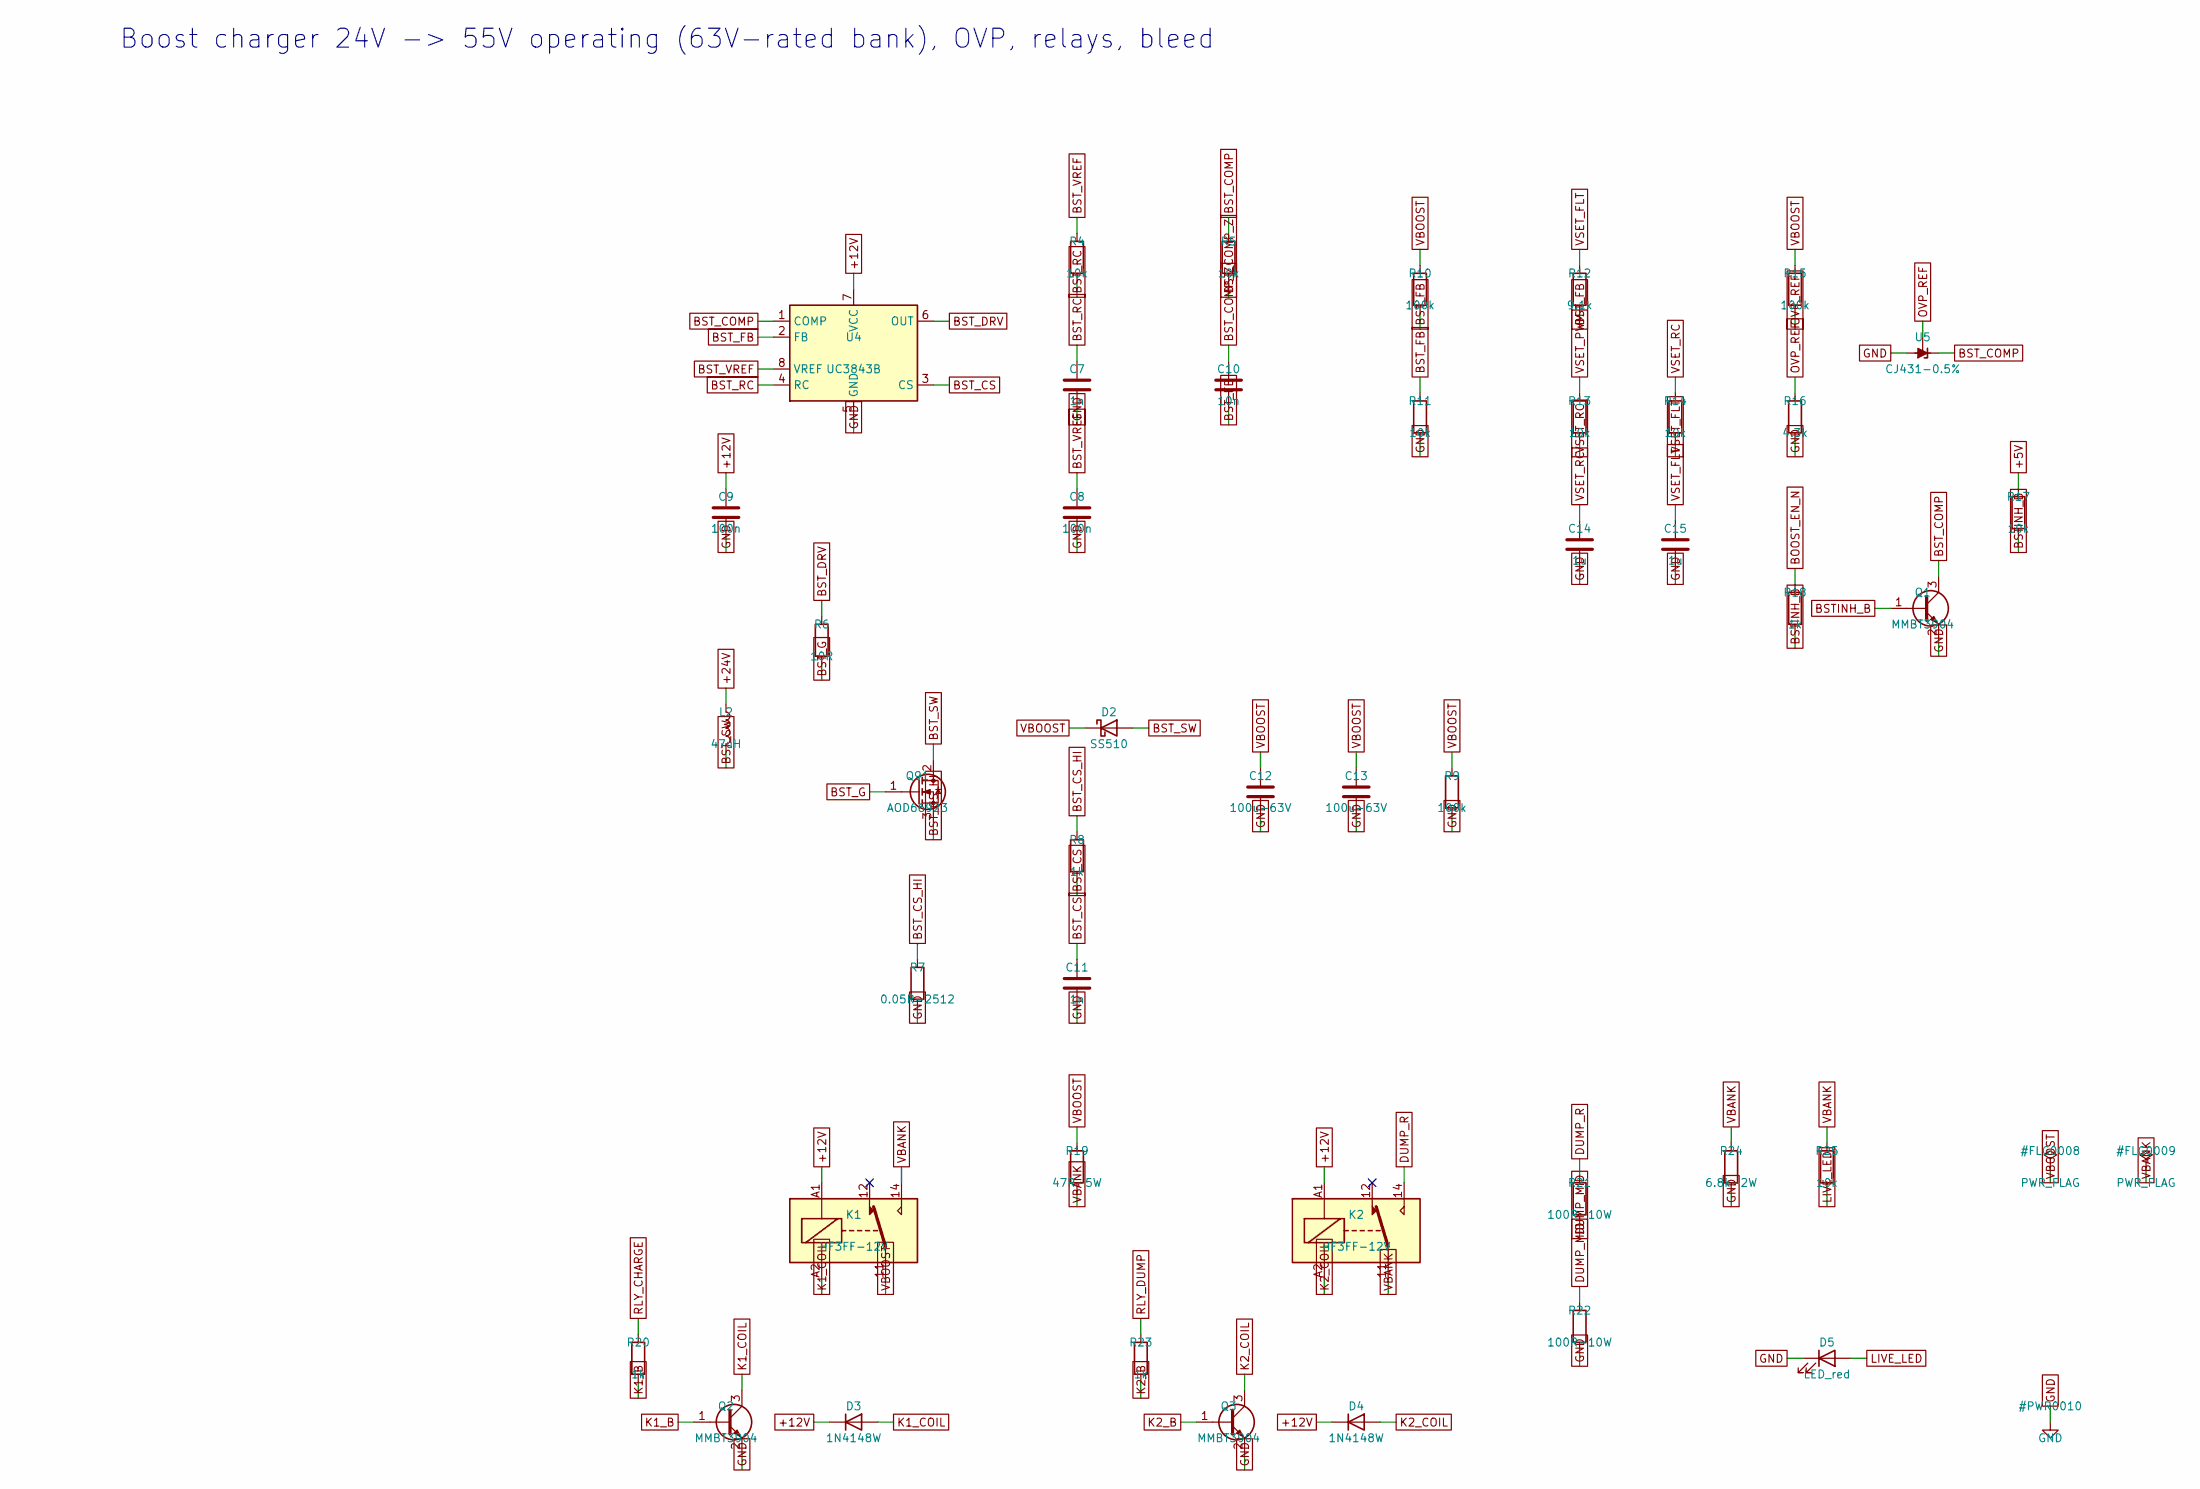
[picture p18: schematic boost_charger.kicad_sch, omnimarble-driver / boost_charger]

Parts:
C7, C11: 1n; C_0603_1608Metric; LCSC C1588
C8, C9: 100n; C_0603_1608Metric; LCSC C14663
C10: 10n; C_0603_1608Metric; LCSC C57112
C12, C13: 100u-63V; CP_Elec_10x10.5; LCSC C28241
C14, C15: 1u; C_0603_1608Metric; LCSC C15849
D2: SS510; D_SMA; LCSC C65010
D3, D4: 1N4148W; D_SOD-123; LCSC C81598
D5: LED_red; LED_0603_1608Metric; LCSC C2286
K1, K2: HF3FF-12V; Relay_HF3FF_T73; LCSC C399561
L2: 47uH; L_12x12mm_H8mm; LCSC C497913
Q1, Q2, Q3: MMBT3904; SOT-23; LCSC C20526
Q91: AOD66923; TO-252-2; LCSC C485687
R4, R5, R11, R13, R14, R17, R25: 10k; R_0603_1608Metric; LCSC C25804
R6: 10R; R_0603_1608Metric; LCSC C22859
R7: 0.05R-2512; R_2512_6332Metric; LCSC C2994645
R8, R18, R20, R23: 1k; R_0603_1608Metric; LCSC C21190
R9, R10, R15: 100k; R_0603_1608Metric; LCSC C25803
R12: 9.1k; R_0603_1608Metric; LCSC C23260
R16: 4.3k; R_0603_1608Metric; LCSC C23159
R19: 47R-5W; R_Box_L26.0mm_W5.0mm_P20.00mm; LCSC C5807995
R21, R22: 100R-10W; R_Radial_Power_L11.0mm_W7.0mm_P5.00mm; LCSC C216413
R24: 6.8k-2W; R_2512_6332Metric; LCSC ORDER-REVIEW
U4: UC3843B; SOIC-8_3.9x4.9mm_P1.27mm; LCSC C16414
U5: CJ431-0.5%; SOT-23; LCSC C3113

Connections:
+5V: R17.1; also elsewhere on the board
+12V: C9.1, D3.1 (K), D4.1 (K), K1.A1, K2.A1, U4.7 (VCC); also elsewhere on the board
+24V: L2.1; also elsewhere on the board
BOOST_EN_N: R18.1; also elsewhere on the board
BSTINH_B: Q1.1 (B), R17.2, R18.2
BST_COMP: Q1.3 (C), R5.1, U4.1 (COMP), U5.1 (K)
BST_COMP_Z: C10.1, R5.2
BST_CS: C11.1, R8.2, U4.3 (CS)
BST_CS_HI: Q91.3 (S), R7.1, R8.1
BST_DRV: R6.1, U4.6 (OUT)
BST_FB: C10.2, R10.2, R11.1, R12.2, U4.2 (FB)
BST_G: Q91.1 (G), R6.2
BST_RC: C7.1, R4.2, U4.4 (RC)
BST_SW: D2.2 (A), L2.2, Q91.2 (D)
BST_VREF: C8.1, R4.1, U4.8 (VREF)
DUMP_MID: R21.2, R22.1
DUMP_R: K2.14, R21.1
GND: C7.2, C8.2, C9.2, C11.2, C12.2, C13.2, C14.2, C15.2, D5.1 (K), Q1.2 (E), Q2.2 (E), Q3.2 (E), R7.2, R9.2, R11.2, R16.2, R22.2, R24.2, U4.5 (GND), U5.3 (A); also elsewhere on the board
K1_B: Q2.1 (B), R20.2
K1_COIL: D3.2 (A), K1.A2, Q2.3 (C)
K2_B: Q3.1 (B), R23.2
K2_COIL: D4.2 (A), K2.A2, Q3.3 (C)
LIVE_LED: D5.2 (A), R25.2
OVP_REF: R15.2, R16.1, U5.2 (REF)
RLY_CHARGE: R20.1; also elsewhere on the board
RLY_DUMP: R23.1; also elsewhere on the board
VBANK: K1.14, K2.11, R19.2, R24.1, R25.1; also elsewhere on the board
VBOOST: C12.1, C13.1, D2.1 (K), K1.11, R9.1, R10.1, R15.1, R19.1
VSET_FLT: C15.1, R12.1, R14.2
VSET_PWM: R13.1; also elsewhere on the board
VSET_RC: C14.1, R13.2, R14.1

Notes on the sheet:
Boost charger 24V -> 55V operating (63V-rated bank), OVP, relays, bleed

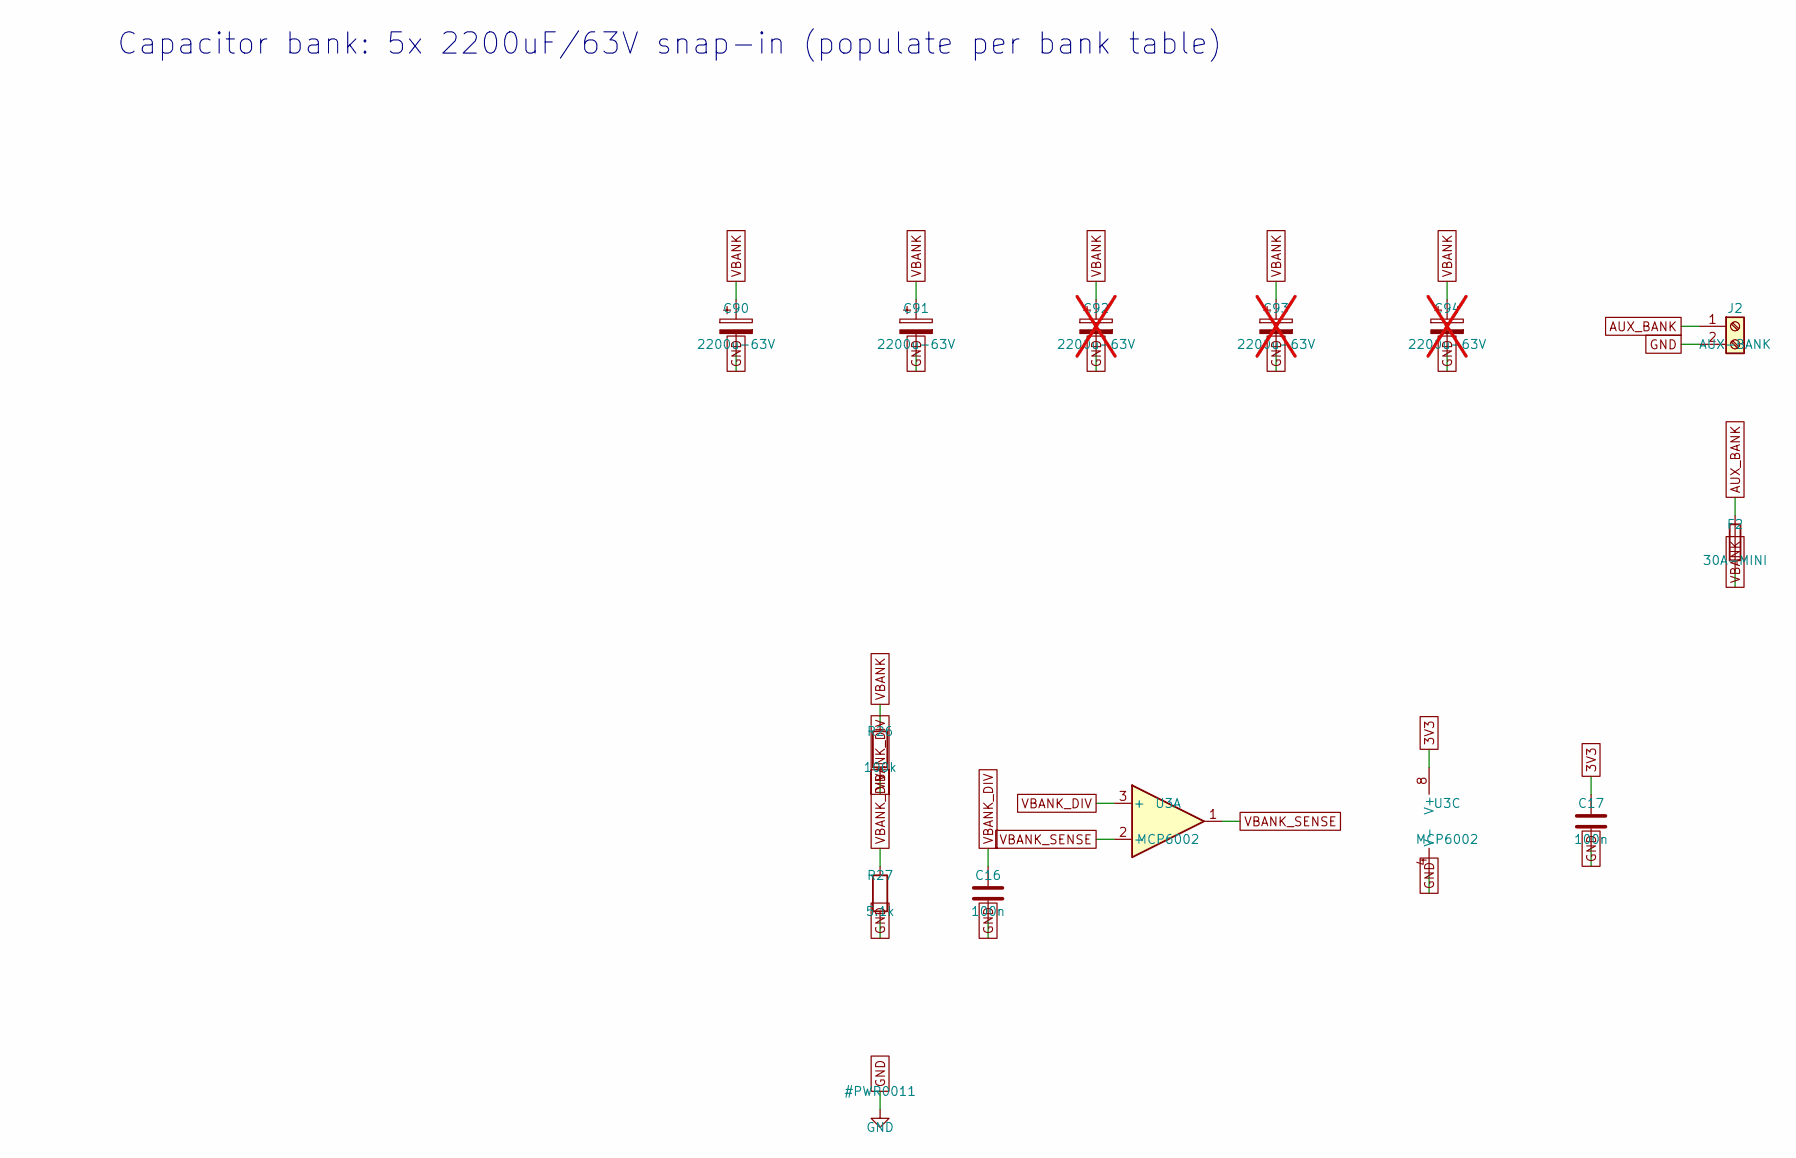
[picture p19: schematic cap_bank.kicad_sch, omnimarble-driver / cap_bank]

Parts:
C16, C17: 100n; C_0603_1608Metric; LCSC C14663
C90, C91: 2200u-63V; CP_Radial_D30.0mm_P10.00mm_SnapIn; LCSC C3724971
C92, C93, C94: 2200u-63V; CP_Radial_D30.0mm_P10.00mm_SnapIn; LCSC C3724971; not fitted
F2: 30A-MINI; Fuseholder_Blade_Mini_Keystone_3568; LCSC C5249699
J2: AUX-BANK; TerminalBarrier_1x02_P9.50mm; LCSC C60785
R26: 100k; R_0603_1608Metric; LCSC C25803
R27: 5.1k; R_0603_1608Metric; LCSC C23186
U3: MCP6002; SOIC-8_3.9x4.9mm_P1.27mm; LCSC C7377

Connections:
3V3: C17.1, U3.8 (V+); also elsewhere on the board
AUX_BANK: F2.1, J2.1
GND: C16.2, C17.2, C90.2, C91.2, C92.2, C93.2, C94.2, J2.2, R27.2, U3.4 (V-); also elsewhere on the board
VBANK: C90.1, C91.1, C92.1, C93.1, C94.1, F2.2, R26.1; also elsewhere on the board
VBANK_DIV: C16.1, R26.2, R27.1, U3.3 (+)
VBANK_SENSE: U3.1, U3.2 (-); also elsewhere on the board

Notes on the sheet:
Capacitor bank: 5x 2200uF/63V snap-in (populate per bank table)

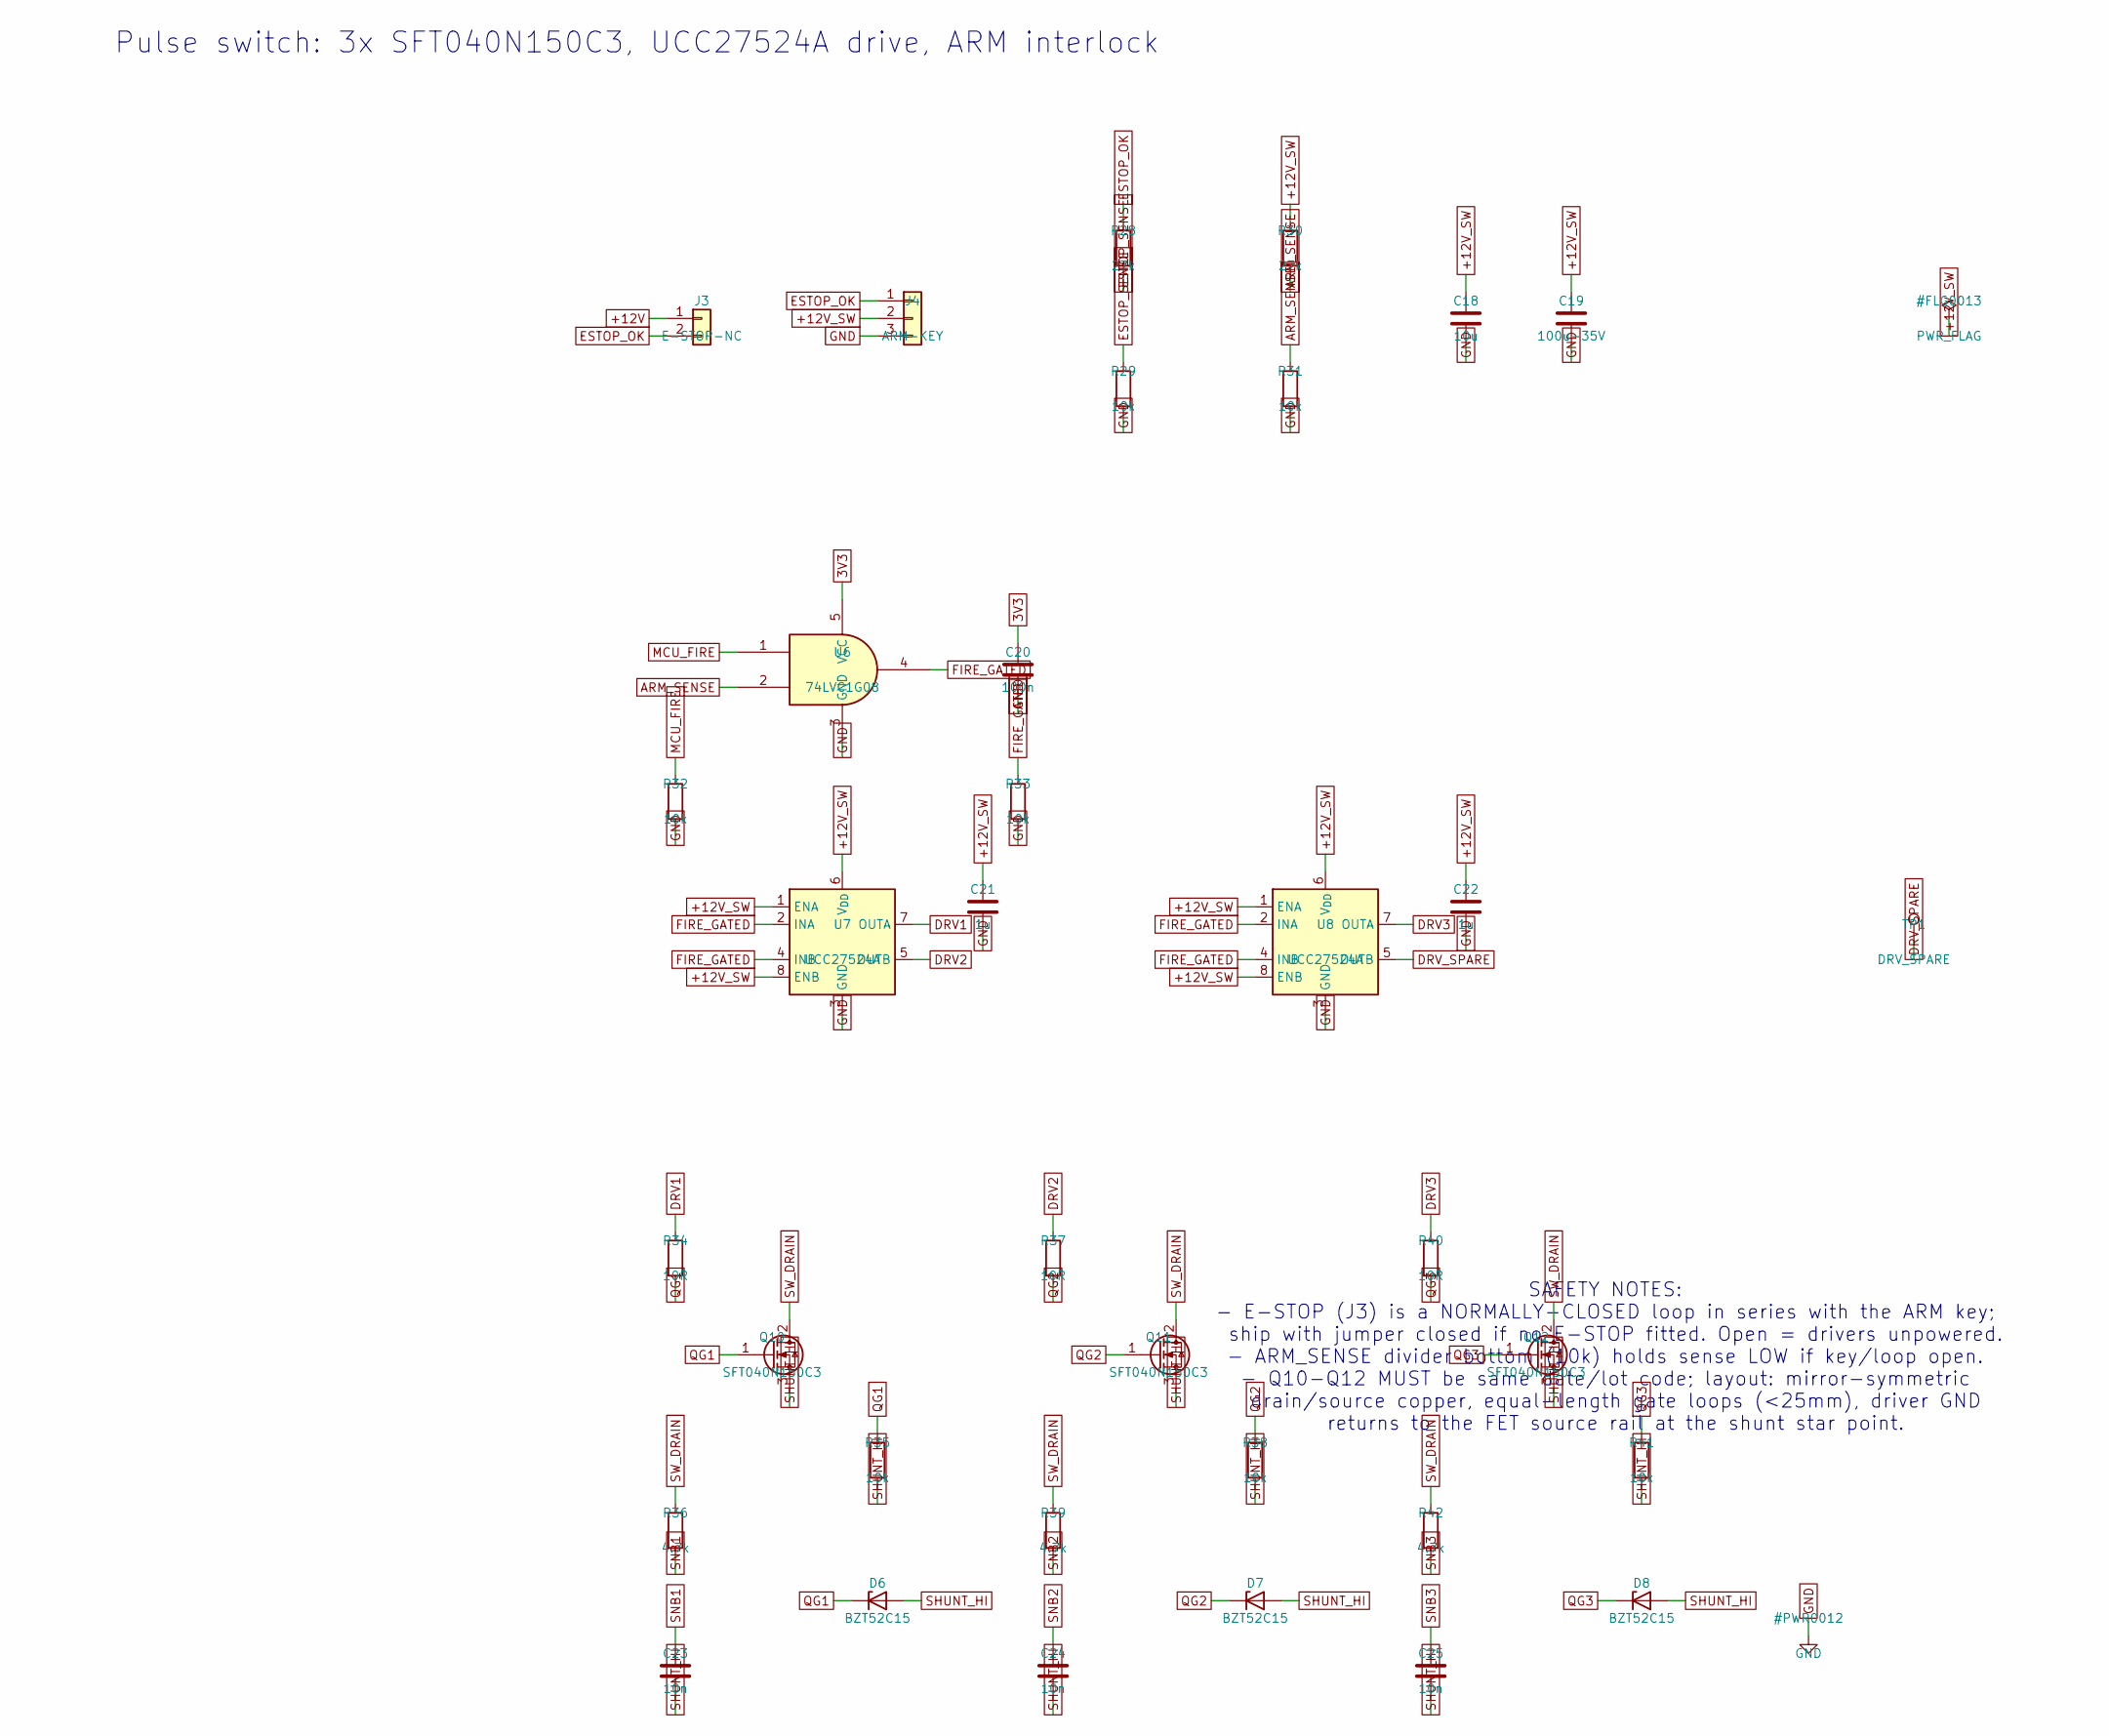
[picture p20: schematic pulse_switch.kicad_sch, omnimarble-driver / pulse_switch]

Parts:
C18: 10u; C_0805_2012Metric; LCSC C15850
C19: 100u-35V; CP_Elec_6.3x7.7; LCSC C176666
C20: 100n; C_0603_1608Metric; LCSC C14663
C21, C22: 1u; C_0603_1608Metric; LCSC C15849
C23, C24, C25: 10n; C_0603_1608Metric; LCSC C57112
D6, D7, D8: BZT52C15; D_SOD-123; LCSC C19077412
J3: E-STOP-NC; PinHeader_1x02_P2.54mm_Vertical
J4: ARM-KEY; PinHeader_1x03_P2.54mm_Vertical
Q10, Q11, Q12: SFT040N150C3; TOLL-8; LCSC C42395334
R28, R30: 27k; R_0603_1608Metric; LCSC C22967
R29, R31, R32, R33, R35, R38, R41: 10k; R_0603_1608Metric; LCSC C25804
R34, R37, R40: 10R; R_0603_1608Metric; LCSC C22859
R36, R39, R42: 4.7k; R_2512_6332Metric; LCSC C23162
TP1: DRV_SPARE; TestPoint_Pad_1.5x1.5mm
U6: 74LVC1G08; SOT-353_SC-70-5; LCSC C7832
U7, U8: UCC27524A; SOIC-8_3.9x4.9mm_P1.27mm; LCSC C185857

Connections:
3V3: C20.1, U6.5 (VCC); also elsewhere on the board
+12V: J3.1; also elsewhere on the board
+12V_SW: C18.1, C19.1, C21.1, C22.1, J4.2, R30.1, U7.1 (ENA), U7.6 (V_{DD}), U7.8 (ENB), U8.1 (ENA), U8.6 (V_{DD}), U8.8 (ENB)
ARM_SENSE: R30.2, R31.1, U6.2; also elsewhere on the board
DRV1: R34.1, U7.7 (OUTA)
DRV2: R37.1, U7.5 (OUTB)
DRV3: R40.1, U8.7 (OUTA)
DRV_SPARE: TP1.1, U8.5 (OUTB)
ESTOP_OK: J3.2, J4.1, R28.1
ESTOP_SENSE: R28.2, R29.1; also elsewhere on the board
FIRE_GATED: R33.1, U6.4, U7.2 (INA), U7.4 (INB), U8.2 (INA), U8.4 (INB)
GND: C18.2, C19.2, C20.2, C21.2, C22.2, J4.3, R29.2, R31.2, R32.2, R33.2, U6.3 (GND), U7.3 (GND), U8.3 (GND); also elsewhere on the board
MCU_FIRE: R32.1, U6.1; also elsewhere on the board
QG1: D6.1 (K), Q10.1 (G), R34.2, R35.1
QG2: D7.1 (K), Q11.1 (G), R37.2, R38.1
QG3: D8.1 (K), Q12.1 (G), R40.2, R41.1
SHUNT_HI: C23.2, C24.2, C25.2, D6.2 (A), D7.2 (A), D8.2 (A), Q10.3 (S), Q11.3 (S), Q12.3 (S), R35.2, R38.2, R41.2; also elsewhere on the board
SNB1: C23.1, R36.2
SNB2: C24.1, R39.2
SNB3: C25.1, R42.2
SW_DRAIN: Q10.2 (D), Q11.2 (D), Q12.2 (D), R36.1, R39.1, R42.1; also elsewhere on the board

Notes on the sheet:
Pulse switch: 3x SFT040N150C3, UCC27524A drive, ARM interlock
SAFETY NOTES: - E-STOP (J3) is a NORMALLY-CLOSED loop in series with the ARM key; ship with jumper closed if no E-STOP fitted. Open = drivers unpowered. - ARM_SENSE divider bottom (10k) holds sense LOW if key/loop open. - Q10-Q12 MUST be same date/lot code; layout: mirror-symmetric drain/source cop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

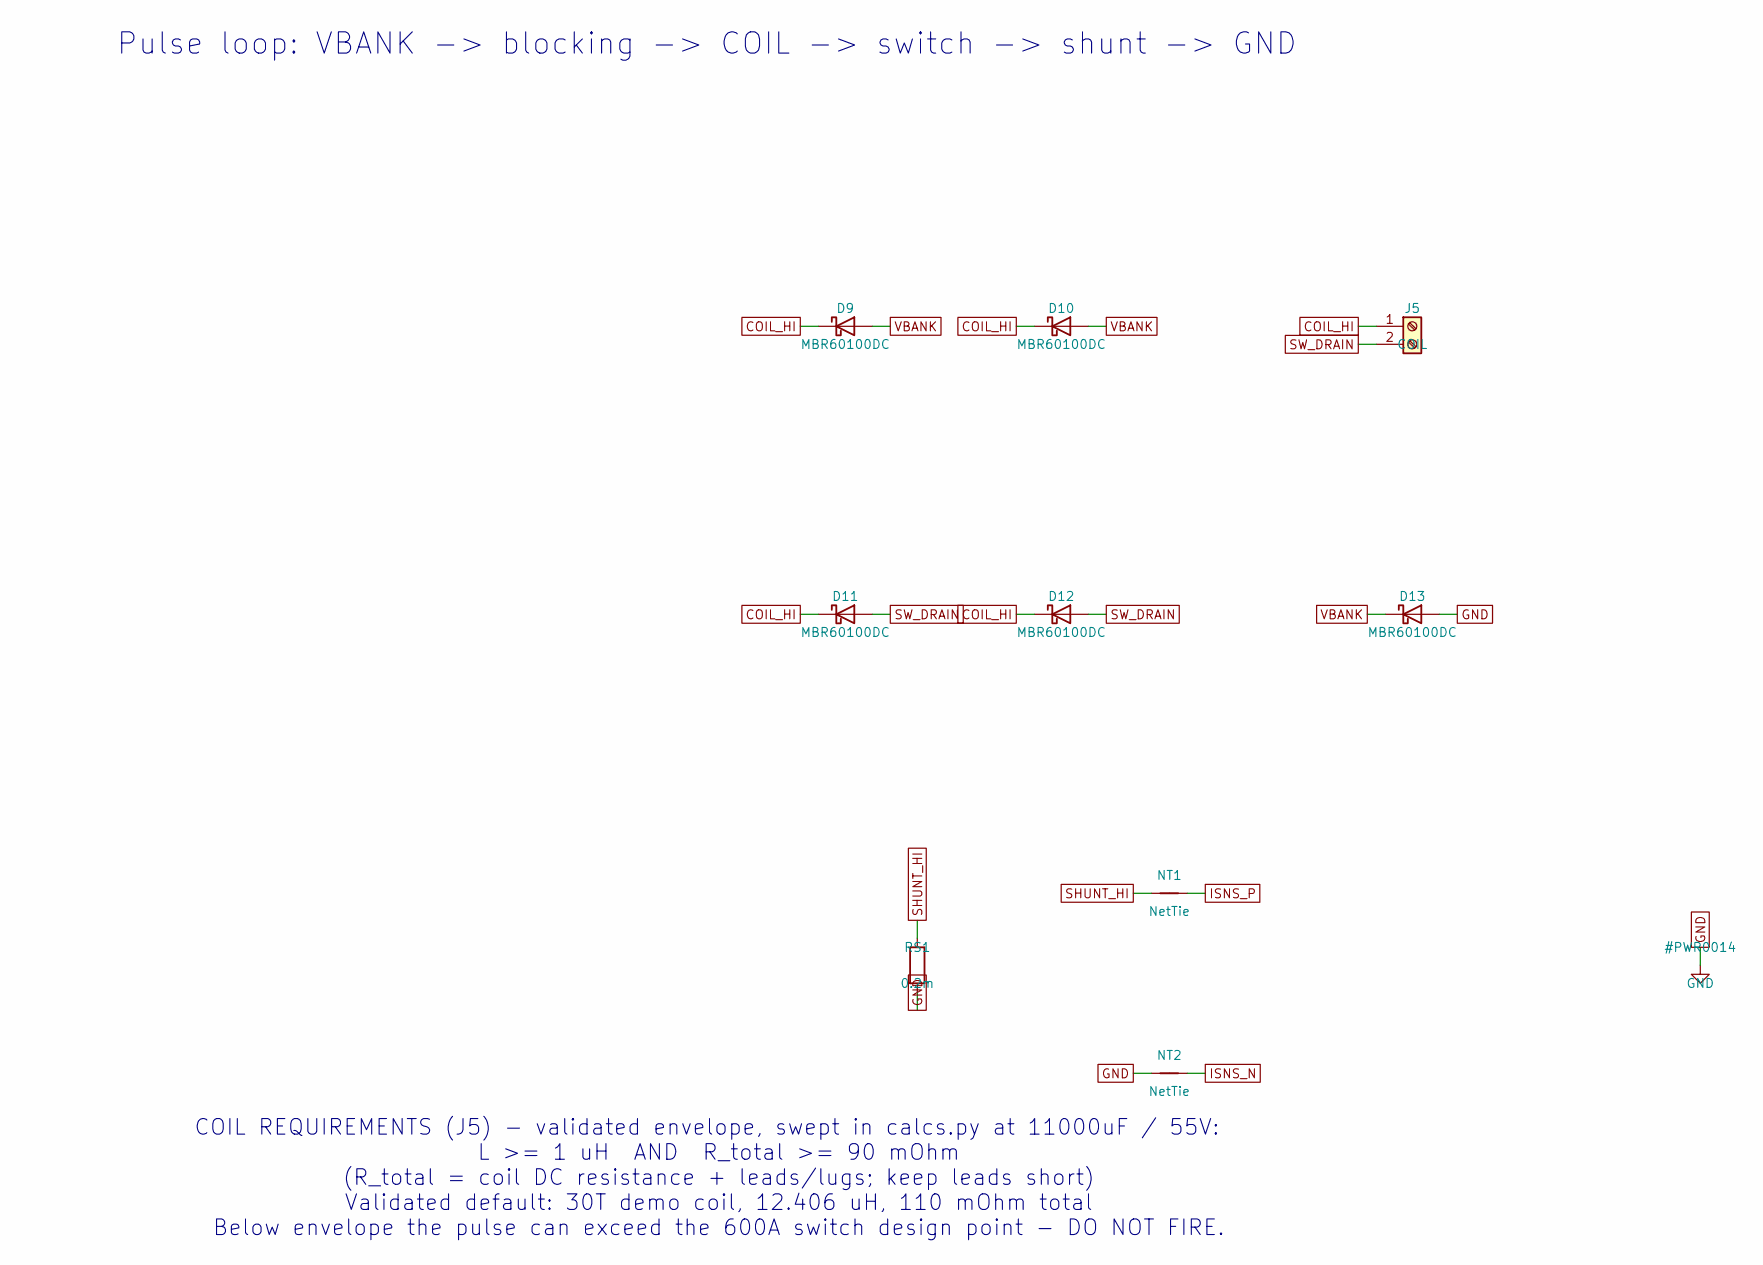
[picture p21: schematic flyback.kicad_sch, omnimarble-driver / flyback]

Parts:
D9, D10, D11, D12, D13: MBR60100DC; D2PAK_MBR60100DC; LCSC C6069541
J5: COIL; TerminalBarrier_1x02_P9.50mm; LCSC C60785
NT1, NT2: NetTie; NetTie-2_SMD_Pad0.5mm
RS1: 0.2m; Shunt_5930; LCSC C469442

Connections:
COIL_HI: D9.1 (K), D10.1 (K), D11.1 (K), D12.1 (K), J5.1
GND: D13.2 (A), NT2.1, RS1.2; also elsewhere on the board
ISNS_N: NT2.2; also elsewhere on the board
ISNS_P: NT1.2; also elsewhere on the board
SHUNT_HI: NT1.1, RS1.1; also elsewhere on the board
SW_DRAIN: D11.2 (A), D12.2 (A), J5.2; also elsewhere on the board
VBANK: D9.2 (A), D10.2 (A), D13.1 (K); also elsewhere on the board

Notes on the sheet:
Pulse loop: VBANK -> blocking -> COIL -> switch -> shunt -> GND
COIL REQUIREMENTS (J5) - validated envelope, swept in calcs.py at 11000uF / 55V: L >= 1 uH AND R_total >= 90 mOhm (R_total = coil DC resistance + leads/lugs; keep leads short) Validated default: 30T demo coil, 12.406 uH, 110 mOhm total Below envelope the pulse can exceed the 600A switch design poin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

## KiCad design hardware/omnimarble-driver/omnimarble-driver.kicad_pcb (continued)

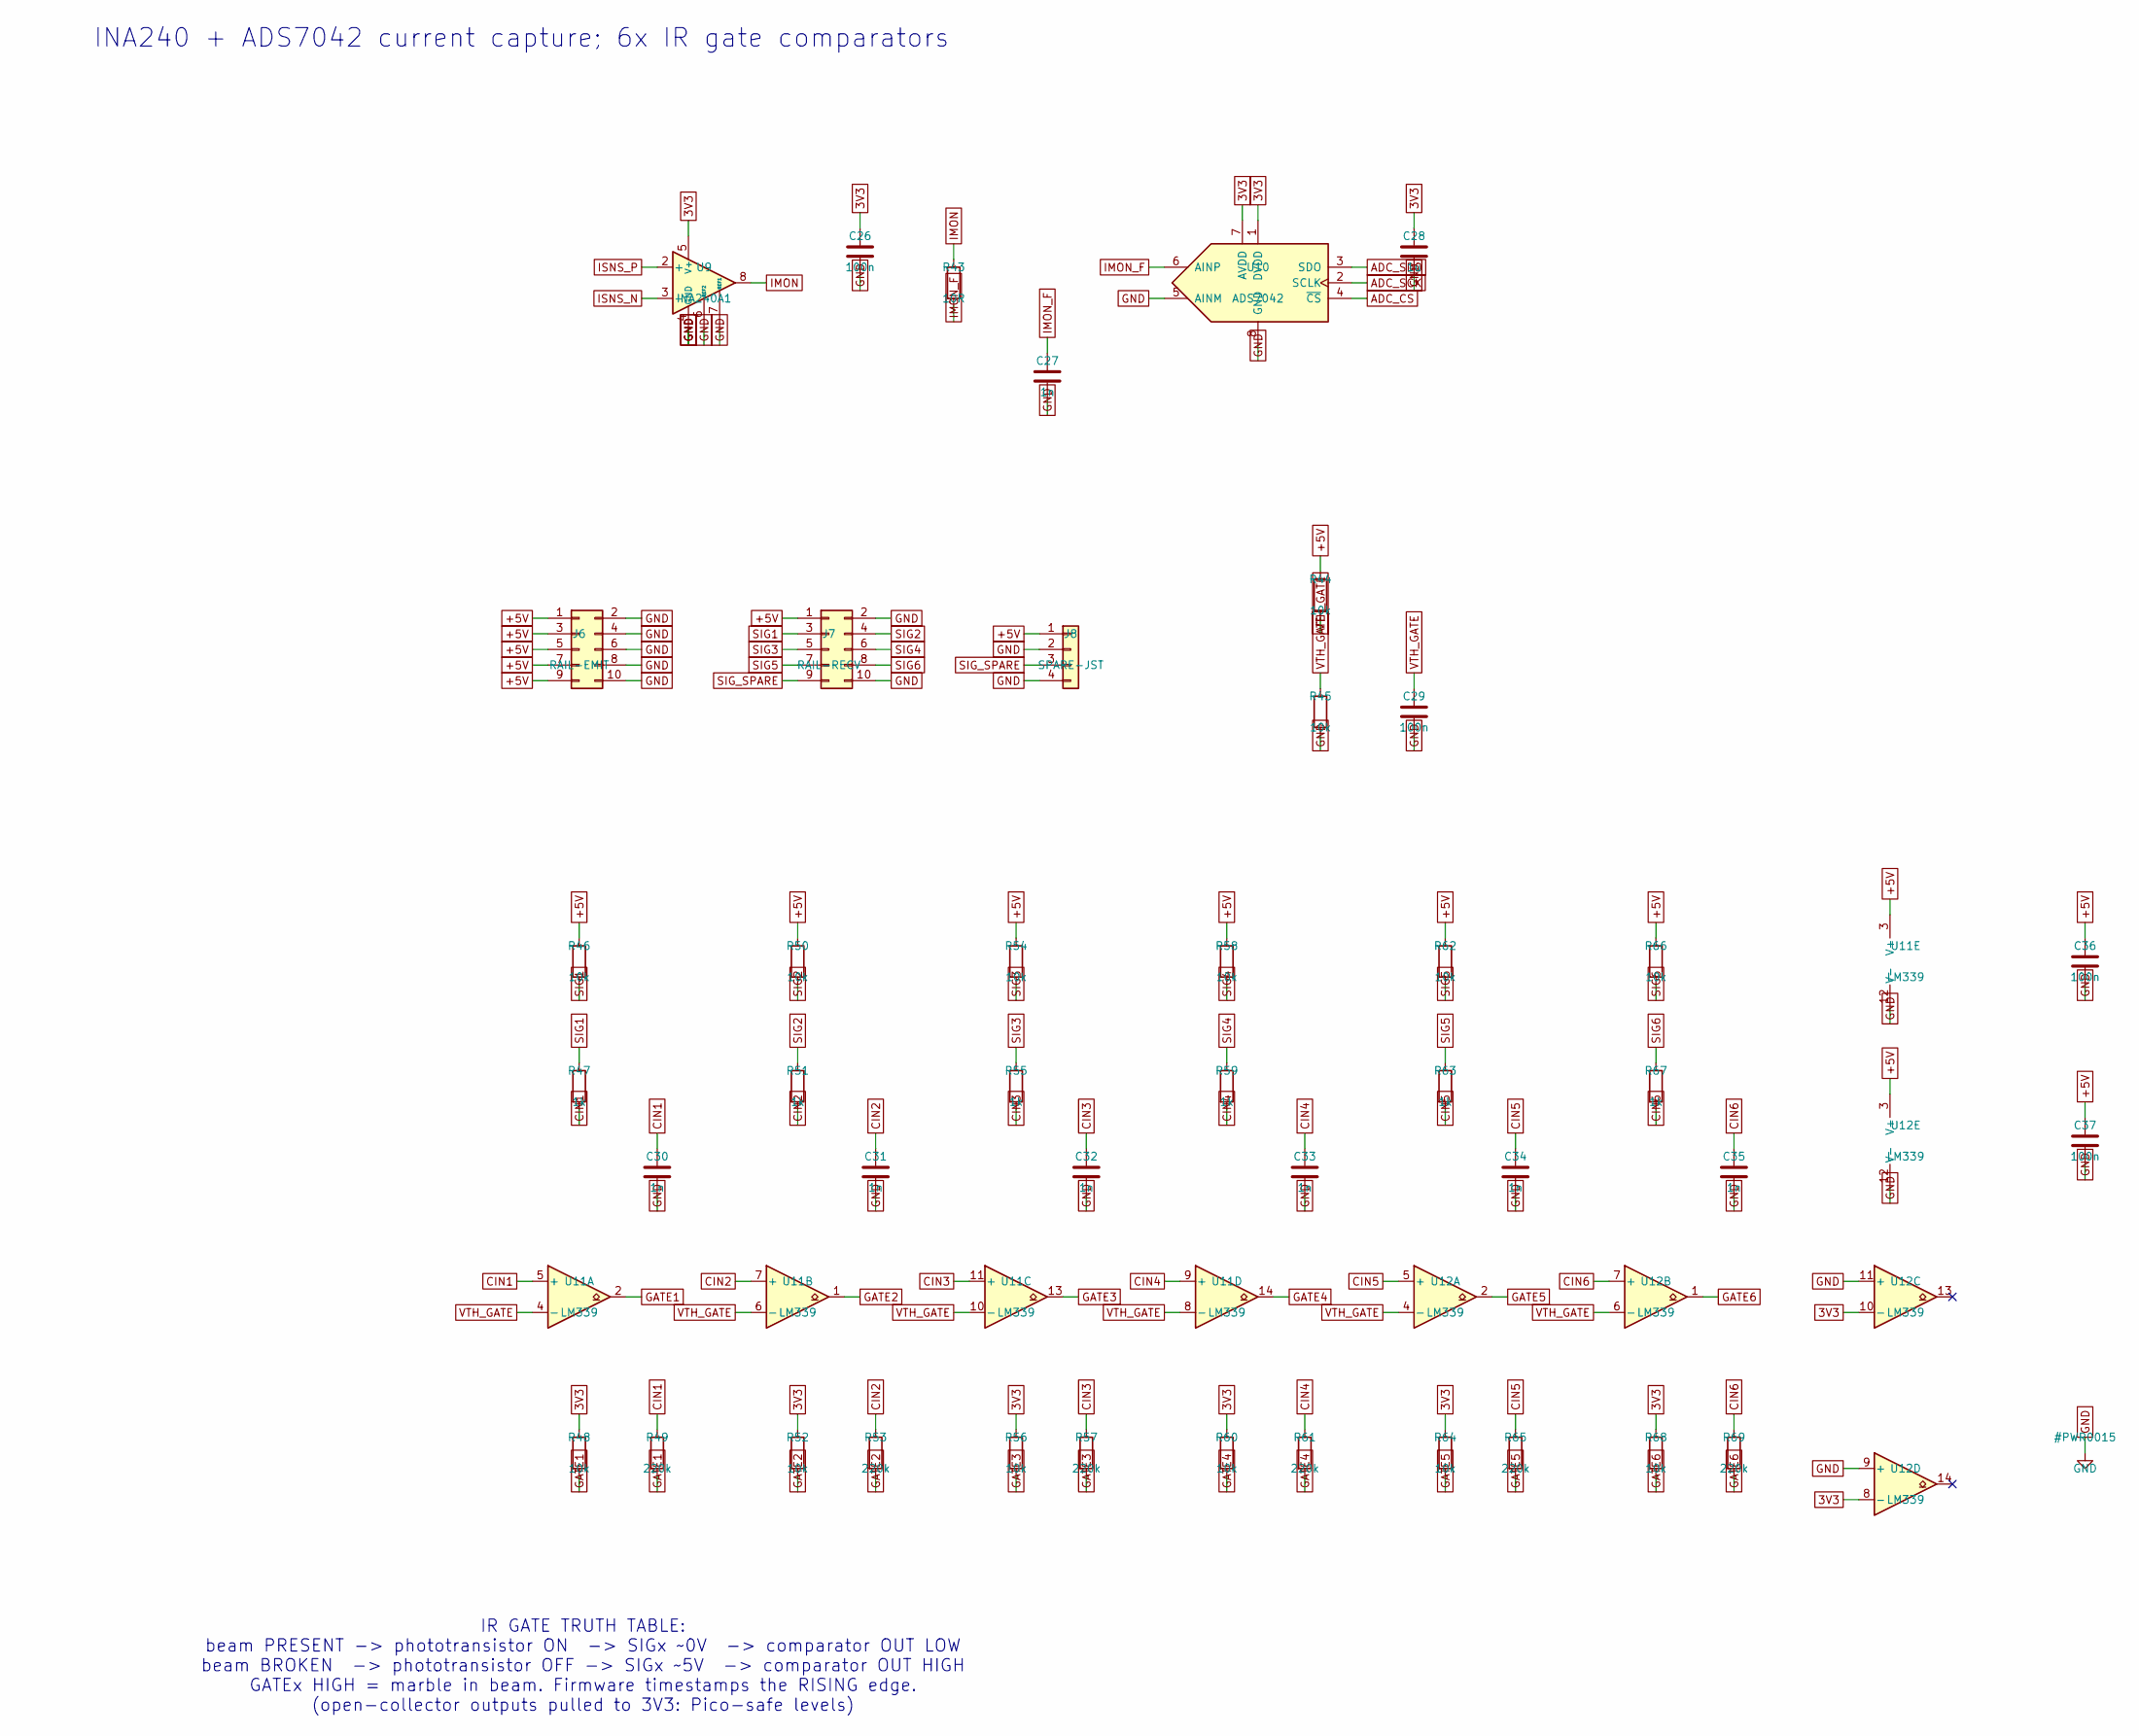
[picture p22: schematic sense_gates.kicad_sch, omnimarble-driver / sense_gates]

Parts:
C26, C29, C36, C37: 100n; C_0603_1608Metric; LCSC C14663
C27, C30, C31, C32, C33, C34, C35: 1n; C_0603_1608Metric; LCSC C1588
C28: 1u; C_0603_1608Metric; LCSC C15849
J6: RAIL-EMIT; IDC-Header_2x05_P2.54mm_Vertical; LCSC C5665
J7: RAIL-RECV; IDC-Header_2x05_P2.54mm_Vertical; LCSC C5665
J8: SPARE-JST; JST_XH_B4B-XH-A_1x04_P2.50mm_Vertical; LCSC C144395
R43: 10R; R_0603_1608Metric; LCSC C22859
R44, R45, R46, R48, R50, R52, R54, R56, R58, R60, R62, R64, R66, R68: 10k; R_0603_1608Metric; LCSC C25804
R47, R51, R55, R59, R63, R67: 1k; R_0603_1608Metric; LCSC C21190
R49, R53, R57, R61, R65, R69: 220k; R_0603_1608Metric; LCSC C22961
U9: INA240A1; TSSOP-8_3x3mm_P0.65mm; LCSC C93965
U10: ADS7042; VSSOP-8_2.3x2mm_P0.5mm; LCSC C701641
U11, U12: LM339; SOIC-14_3.9x8.7mm_P1.27mm; LCSC C7948

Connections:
3V3: C26.1, C28.1, R48.1, R52.1, R56.1, R60.1, R64.1, R68.1, U9.5 (V+), U10.1 (DVDD), U10.7 (AVDD), U12.8 (-), U12.10 (-); also elsewhere on the board
+5V: C36.1, C37.1, J6.1, J6.3, J6.5, J6.7, J6.9, J7.1, J8.1, R44.1, R46.1, R50.1, R54.1, R58.1, R62.1, R66.1, U11.3 (V+), U12.3 (V+); also elsewhere on the board
ADC_CS: U10.4 (~CS); also elsewhere on the board
ADC_SCK: U10.2 (SCLK); also elsewhere on the board
ADC_SDO: U10.3 (SDO); also elsewhere on the board
CIN1: C30.1, R47.2, R49.1, U11.5 (+)
CIN2: C31.1, R51.2, R53.1, U11.7 (+)
CIN3: C32.1, R55.2, R57.1, U11.11 (+)
CIN4: C33.1, R59.2, R61.1, U11.9 (+)
CIN5: C34.1, R63.2, R65.1, U12.5 (+)
CIN6: C35.1, R67.2, R69.1, U12.7 (+)
GATE1: R48.2, R49.2, U11.2; also elsewhere on the board
GATE2: R52.2, R53.2, U11.1; also elsewhere on the board
GATE3: R56.2, R57.2, U11.13; also elsewhere on the board
GATE4: R60.2, R61.2, U11.14; also elsewhere on the board
GATE5: R64.2, R65.2, U12.2; also elsewhere on the board
GATE6: R68.2, R69.2, U12.1; also elsewhere on the board
GND: C26.2, C27.2, C28.2, C29.2, C30.2, C31.2, C32.2, C33.2, C34.2, C35.2, C36.2, C37.2, J6.2, J6.4, J6.6, J6.8, J6.10, J7.2, J7.10, J8.2, J8.4, R45.2, U9.1 (GND), U9.4 (GND), U9.6 (REF2), U9.7 (REF1), U10.5 (AINM), U10.8 (GND), U11.12 (V-), U12.9 (+), U12.11 (+), U12.12 (V-); also elsewhere on the board
IMON: R43.1, U9.8
IMON_F: C27.1, R43.2, U10.6 (AINP)
ISNS_N: U9.3 (-); also elsewhere on the board
ISNS_P: U9.2 (+); also elsewhere on the board
SIG1: J7.3, R46.2, R47.1
SIG2: J7.4, R50.2, R51.1
SIG3: J7.5, R54.2, R55.1
SIG4: J7.6, R58.2, R59.1
SIG5: J7.7, R62.2, R63.1
SIG6: J7.8, R66.2, R67.1
SIG_SPARE: J7.9, J8.3
VTH_GATE: C29.1, R44.2, R45.1, U11.4 (-), U11.6 (-), U11.8 (-), U11.10 (-), U12.4 (-), U12.6 (-)

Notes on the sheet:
INA240 + ADS7042 current capture; 6x IR gate comparators
IR GATE TRUTH TABLE: beam PRESENT -> phototransistor ON -> SIGx ~0V -> comparator OUT LOW beam BROKEN -> phototransistor OFF -> SIGx ~5V -> comparator OUT HIGH GATEx HIGH = marble in beam. Firmware timestamps the RISING edge. (open-collector outputs pulled to 3V3: Pico-safe levels)

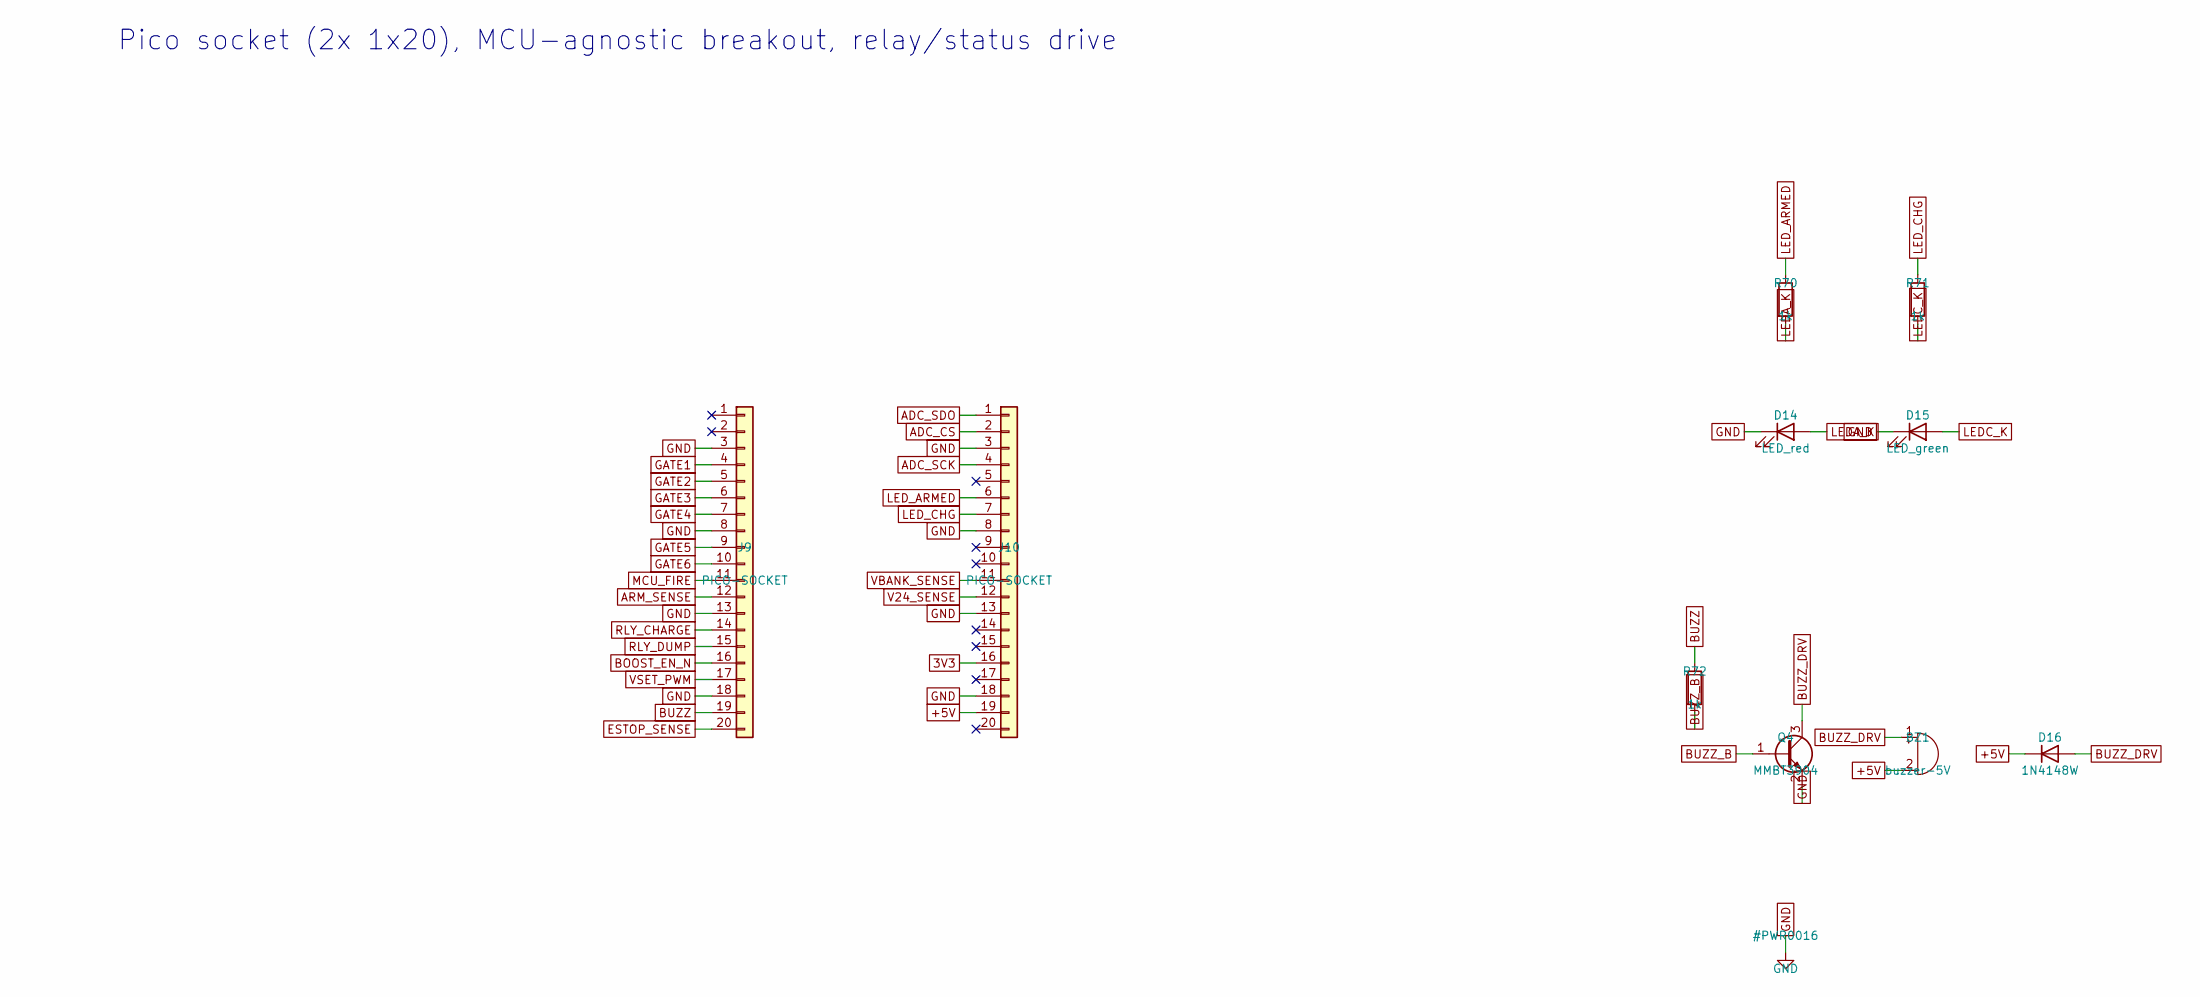
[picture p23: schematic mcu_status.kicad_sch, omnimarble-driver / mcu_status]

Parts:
BZ1: buzzer-5V; Buzzer_12x9.5RM7.6; LCSC C409842
D14: LED_red; LED_0603_1608Metric; LCSC C2286
D15: LED_green; LED_0603_1608Metric; LCSC C72043
D16: 1N4148W; D_SOD-123; LCSC C81598
J9, J10: PICO-SOCKET; PinSocket_1x20_P2.54mm_Vertical; LCSC C50984
Q4: MMBT3904; SOT-23; LCSC C20526
R70, R71, R72: 1k; R_0603_1608Metric; LCSC C21190

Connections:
3V3: J10.16; also elsewhere on the board
+5V: BZ1.2 (-), D16.1 (K), J10.19; also elsewhere on the board
ADC_CS: J10.2; also elsewhere on the board
ADC_SCK: J10.4; also elsewhere on the board
ADC_SDO: J10.1; also elsewhere on the board
ARM_SENSE: J9.12; also elsewhere on the board
BOOST_EN_N: J9.16; also elsewhere on the board
BUZZ: J9.19, R72.1
BUZZ_B: Q4.1 (B), R72.2
BUZZ_DRV: BZ1.1 (+), D16.2 (A), Q4.3 (C)
ESTOP_SENSE: J9.20; also elsewhere on the board
GATE1: J9.4; also elsewhere on the board
GATE2: J9.5; also elsewhere on the board
GATE3: J9.6; also elsewhere on the board
GATE4: J9.7; also elsewhere on the board
GATE5: J9.9; also elsewhere on the board
GATE6: J9.10; also elsewhere on the board
GND: D14.1 (K), D15.1 (K), J9.3, J9.8, J9.13, J9.18, J10.3, J10.8, J10.13, J10.18, Q4.2 (E); also elsewhere on the board
LEDA_K: D14.2 (A), R70.2
LEDC_K: D15.2 (A), R71.2
LED_ARMED: J10.6, R70.1
LED_CHG: J10.7, R71.1
MCU_FIRE: J9.11; also elsewhere on the board
RLY_CHARGE: J9.14; also elsewhere on the board
RLY_DUMP: J9.15; also elsewhere on the board
V24_SENSE: J10.12; also elsewhere on the board
VBANK_SENSE: J10.11; also elsewhere on the board
VSET_PWM: J9.17; also elsewhere on the board

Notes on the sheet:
Pico socket (2x 1x20), MCU-agnostic breakout, relay/status drive

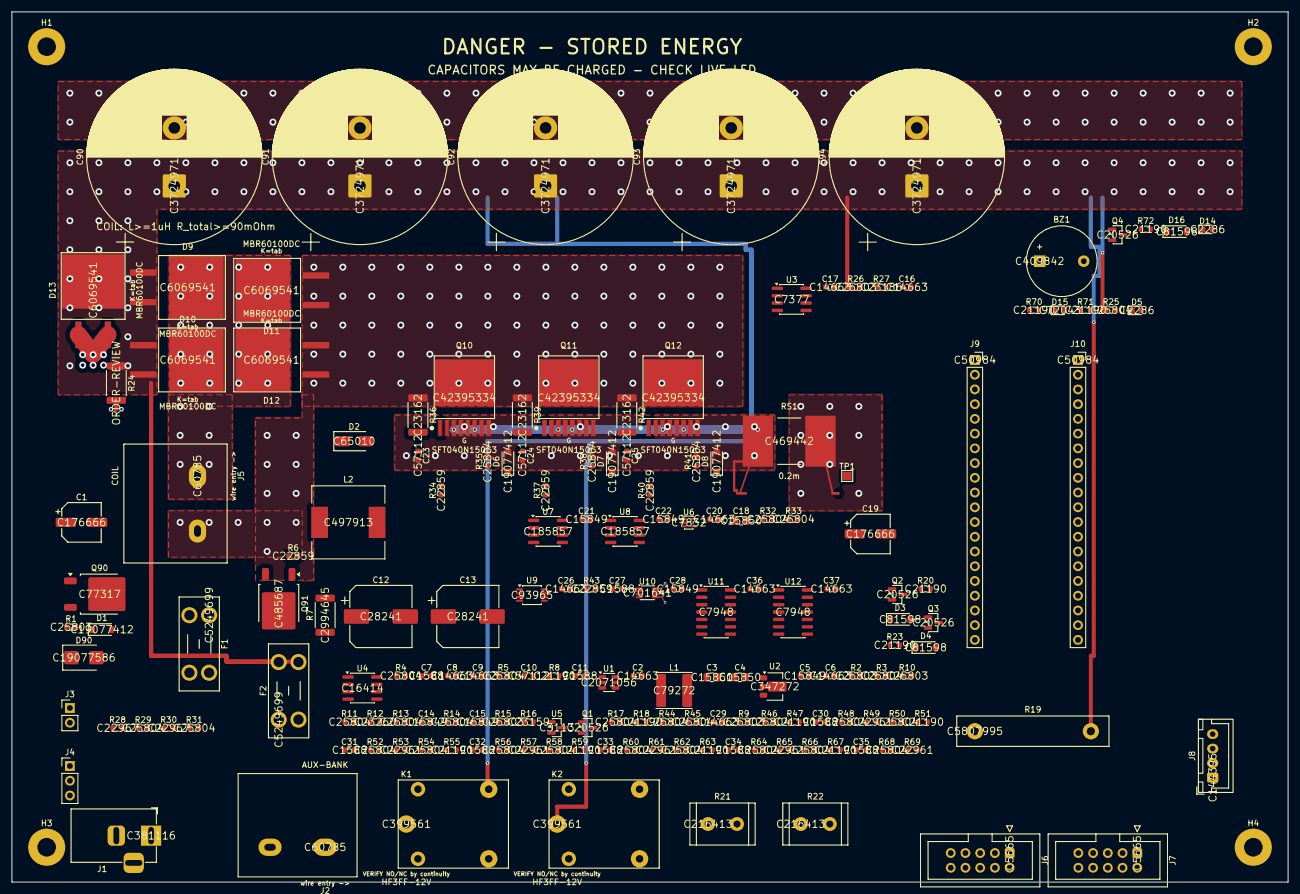
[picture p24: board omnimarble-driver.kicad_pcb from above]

Board: 4 copper layers, 220.0 x 150.0 mm, 177 parts (0 on the bottom side), 95 nets.

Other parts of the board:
H1, H2, H3, H4: MountingHole_3.2mm_M3_Pad

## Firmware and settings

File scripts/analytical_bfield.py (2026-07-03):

"""Analytical B-field computation for a finite solenoid using Biot-Savart with elliptic integrals.

All units in mm, A, T (Tesla). Forces in mN.
μ₀ = 4π × 10⁻⁷ T·m/A = 4π × 10⁻⁴ T·mm/A
"""

import json
import math
from pathlib import Path

import matplotlib.pyplot as plt
import numpy as np
from scipy.special import ellipe, ellipk

ROOT = Path(__file__).resolve().parent.parent
CONFIG_PATH = ROOT / "config" / "coil_params.json"
PLOTS_DIR = ROOT / "results" / "plots"

MU_0_MM = 4 * math.pi * 1e-4  # T·mm/A


def single_loop_field(r: float, z: float, R: float, I: float) -> tuple[float, float]:
    """Compute B_r and B_z from a single circular current loop.

    Args:
        r: radial distance from axis (mm)
        z: axial distance from loop plane (mm)
        R: loop radius (mm)
        I: current (A)

    Returns:
        (B_r, B_z) in Tesla
    """
    r = abs(r)

    if r < 1e-10:
        # On axis — simplified formula
        B_z = MU_0_MM * I * R**2 / (2 * (R**2 + z**2) ** 1.5)
        return 0.0, B_z

    # Compute parameter m = k² for scipy's ellipk/ellipe
    alpha_sq = R**2 + r**2 + z**2 - 2 * R * r
    beta_sq = R**2 + r**2 + z**2 + 2 * R * r

    if beta_sq < 1e-20:
        return 0.0, 0.0

    m = 1.0 - alpha_sq / beta_sq  # m = 4Rr / beta²
    m = np.clip(m, 0, 1 - 1e-12)

    K = ellipk(m)
    E = ellipe(m)

    beta = math.sqrt(beta_sq)
    prefactor = MU_0_MM * I / (2 * math.pi)

    # B_z
    B_z = prefactor / beta * (K + (R**2 - r**2 - z**2) / alpha_sq * E)

    # B_r
    B_r = prefactor * z / (r * beta) * (-K + (R**2 + r**2 + z**2) / alpha_sq * E)

    return float(B_r), float(B_z)


def solenoid_field(r: float, z: float, coil_params: dict) -> tuple[float, float]:
    """Compute B-field of a finite solenoid by summing loop contributions.

    The solenoid is centered at origin, extending from -L/2 to L/2 along z-axis.
    Uses the mean coil radius = (inner + outer) / 2.

    NOTE (model inconsistency, documented in hardware/README.md): this
    places every turn at R_mean = (inner+outer)/2 = 15mm for the default
    config, while the winding/inductance model (coil_physics.py,
    rlc_circuit.py) assumes a single layer on the 12mm inner former
    (wire centers ~12.4mm). Physical builds should match THIS field
    geometry (wire centers at R_mean) and reconcile L/R by measurement.

    Args:
        r: radial distance (mm)
        z: axial position (mm)
        coil_params: dict with coil parameters

    Returns:
        (B_r, B_z) in Tesla
    """
    N = coil_params["num_turns"]
    L = coil_params["length_mm"]
    R_mean = (coil_params["inner_radius_mm"] + coil_params["outer_radius_mm"]) / 2
    I = coil_params.get("current_A", coil_params.get("max_current_A", 10.0))

    # Each turn contributes current I, distributed over length L
    # Position each loop evenly along the solenoid
    z_positions = np.linspace(-L / 2, L / 2, N)

    B_r_total = 0.0
    B_z_total = 0.0

    for z_loop in z_positions:
        dz = z - z_loop
        b_r, b_z = single_loop_field(r, dz, R_mean, I)
        B_r_total += b_r
        B_z_total += b_z

    return B_r_total, B_z_total


def solenoid_field_gradient(
    r: float, z: float, coil_params: dict, dr: float = 0.1, dz: float = 0.1
) -> tuple[float, float, float, float]:
    """Compute B-field gradients via central finite differences.

    Returns:
        (dBr_dr, dBr_dz, dBz_dr, dBz_dz)
    """
    # dBr/dr
    Br_p, _ = solenoid_field(r + dr, z, coil_params)
    Br_m, _ = solenoid_field(max(r - dr, 0), z, coil_params)
    dBr_dr = (Br_p - Br_m) / (2 * dr) if r > dr else (Br_p - Br_m) / (r + dr)

    # dBr/dz
    Br_zp, _ = solenoid_field(r, z + dz, coil_params)
    Br_zm, _ = solenoid_field(r, z - dz, coil_params)
    dBr_dz = (Br_zp - Br_zm) / (2 * dz)

    # dBz/dr
    _, Bz_p = solenoid_field(r + dr, z, coil_params)
    _, Bz_m = solenoid_field(max(r - dr, 0), z, coil_params)
    dBz_dr = (Bz_p - Bz_m) / (2 * dr) if r > dr else (Bz_p - Bz_m) / (r + dr)

    # dBz/dz
    _, Bz_zp = solenoid_field(r, z + dz, coil_params)
    _, Bz_zm = solenoid_field(r, z - dz, coil_params)
    dBz_dz = (Bz_zp - Bz_zm) / (2 * dz)

    return dBr_dr, dBr_dz, dBz_dr, dBz_dz


def ferromagnetic_force(
    r: float, z: float, marble_radius: float, coil_params: dict,
    chi_eff: float = 3.0,
) -> tuple[float, float]:
    """Compute force on a ferromagnetic sphere in the B-field.

    F = (χ_eff * V / μ₀) * (B·∇)B

    Args:
        r: radial position (mm)
        z: axial position (mm)
        marble_radius: sphere radius (mm)
        coil_params: coil parameters
        chi_eff: effective susceptibility (dimensionless, ~3 for steel bearing, demagnetization-corrected)

    Returns:
        (F_r, F_z) in mN
    """
    V = (4 / 3) * math.pi * marble_radius**3  # mm³

    B_r, B_z = solenoid_field(r, z, coil_params)
    dBr_dr, dBr_dz, dBz_dr, dBz_dz = solenoid_field_gradient(r, z, coil_params)

    # (B·∇)B components in cylindrical coords
    # F_r = (χV/μ₀) * (B_r * dB_r/dr + B_z * dB_r/dz)
    # F_z = (χV/μ₀) * (B_r * dB_z/dr + B_z * dB_z/dz)
    prefactor = chi_eff * V / MU_0_MM  # mm² · A (gives force in T²·mm²/T·mm·A⁻¹ → needs unit conversion)

    # Convert: T² · mm² / (T·mm/A) = T·A·mm = 1e-3 N·mm⁻¹ · mm = mN... let's be careful
    # B is in T, gradient is T/mm, V in mm³, μ₀ in T·mm/A
    # F = χ·V/μ₀ · B · dB/dx → [mm³/(T·mm/A)] · T · T/mm = mm³·A·T/(T·mm²) = A·T·mm
    # 1 A·T·mm = 1 A · (kg/(A·s²)) · (1e-3 m) = 1e-3 kg·m/s² = 1e-3 N = 1 mN ✓

    F_r = prefactor * (B_r * dBr_dr + B_z * dBr_dz)  # mN
    F_z = prefactor * (B_r * dBz_dr + B_z * dBz_dz)  # mN

    return float(F_r), float(F_z)


def solenoid_field_batch(r_arr, z_arr, coil_params):
    """Vectorized B-field computation for arrays of (r, z) points.

    ~100x faster than calling solenoid_field() in a Python loop.
    Computes all N_turns loop contributions for all points simultaneously
    using numpy broadcasting.

    Args:
        r_arr: (M,) array of radial positions (mm)
        z_arr: (M,) array of axial positions (mm)
        coil_params: dict with coil parameters

    Returns:
        (Br, Bz) arrays of shape (M,) in Tesla
    """
    N = coil_params["num_turns"]
    L = coil_params["length_mm"]
    R = (coil_params["inner_radius_mm"] + coil_params["outer_radius_mm"]) / 2
    I = coil_params.get("current_A", coil_params.get("max_current_A", 10.0))

    r = np.abs(np.asarray(r_arr, dtype=np.float64))  # (M,)
    z = np.asarray(z_arr, dtype=np.float64)            # (M,)
    z_loops = np.linspace(-L / 2, L / 2, N)           # (N,)

    # dz[i, j] = z[i] - z_loops[j], shape (M, N)
    dz = z[:, None] - z_loops[None, :]

    # Broadcast r to (M, N)
    r_2d = r[:, None] * np.ones(N)[None, :]

    # Elliptic integral parameters
    alpha_sq = R**2 + r_2d**2 + dz**2 - 2 * R * r_2d  # (M, N)
    beta_sq = R**2 + r_2d**2 + dz**2 + 2 * R * r_2d   # (M, N)
    beta_sq = np.maximum(beta_sq, 1e-30)

    m = 1.0 - alpha_sq / beta_sq
    m = np.clip(m, 0, 1 - 1e-12)

    K = ellipk(m)
    E = ellipe(m)

    beta = np.sqrt(beta_sq)
    alpha_sq_safe = np.where(np.abs(alpha_sq) < 1e-30, 1e-30, alpha_sq)
    prefactor = MU_0_MM * I / (2 * math.pi)

    # Bz from each loop
    Bz_loops = prefactor / beta * (K + (R**2 - r_2d**2 - dz**2) / alpha_sq_safe * E)

    # Br from each loop (handle r=0 case)
    r_safe = np.where(r_2d < 1e-10, 1e-10, r_2d)
    Br_loops = prefactor * dz / (r_safe * beta) * (-K + (R**2 + r_2d**2 + dz**2) / alpha_sq_safe * E)

    # On-axis: Br=0, Bz uses simplified formula
    on_axis = r_2d < 1e-10
    Bz_on_axis = MU_0_MM * I * R**2 / (2 * (R**2 + dz**2) ** 1.5)
    Bz_loops = np.where(on_axis, Bz_on_axis, Bz_loops)
    Br_loops = np.where(on_axis, 0.0, Br_loops)

    # Sum over loops
    Br_total = Br_loops.sum(axis=1)  # (M,)
    Bz_total = Bz_loops.sum(axis=1)  # (M,)

    return Br_total.astype(np.float64), Bz_total.astype(np.float64)


def solenoid_field_gradient_batch(r_arr, z_arr, coil_params, dr=0.1, dz_step=0.1):
    """Vectorized B-field gradient computation via central finite differences.

    Returns:
        (dBr_dr, dBr_dz, dBz_dr, dBz_dz) arrays of shape (M,)
    """
    r = np.asarray(r_arr, dtype=np.float64)
    z = np.asarray(z_arr, dtype=np.float64)

    # dBz/dz
    _, Bz_zp = solenoid_field_batch(r, z + dz_step, coil_params)
    _, Bz_zm = solenoid_field_batch(r, z - dz_step, coil_params)
    dBz_dz = (Bz_zp - Bz_zm) / (2 * dz_step)

    # dBz/dr
    _, Bz_rp = solenoid_field_batch(r + dr, z, coil_params)
    _, Bz_rm = solenoid_field_batch(np.maximum(r - dr, 0), z, coil_params)
    # Use one-sided diff near r=0
    denom_r = np.where(r > dr, 2 * dr, r + dr)
    dBz_dr = (Bz_rp - Bz_rm) / denom_r

    # dBr/dr
    Br_rp, _ = solenoid_field_batch(r + dr, z, coil_params)
    Br_rm, _ = solenoid_field_batch(np.maximum(r - dr, 0), z, coil_params)
    dBr_dr = (Br_rp - Br_rm) / denom_r

    # dBr/dz
    Br_zp, _ = solenoid_field_batch(r, z + dz_step, coil_params)
    Br_zm, _ = solenoid_field_batch(r, z - dz_step, coil_params)
    dBr_dz = (Br_zp - Br_zm) / (2 * dz_step)

    return dBr_dr, dBr_dz, dBz_dr, dBz_dz


def validate_and_plot(coil_params: dict):
    """Generate validation plots for the B-field computation."""
    PLOTS_DIR.mkdir(parents=True, exist_ok=True)

    # 1. B-field contour map
    r_grid = np.linspace(0, 60, 100)
    z_grid = np.linspace(-80, 80, 200)
    R, Z = np.meshgrid(r_grid, z_grid)

    Br = np.zeros_like(R)
    Bz = np.zeros_like(R)
    Bmag = np.zeros_like(R)

    for i in range(R.shape[0]):
        for j in range(R.shape[1]):
            br, bz = solenoid_field(R[i, j], Z[i, j], coil_params)
            Br[i, j] = br
            Bz[i, j] = bz
            Bmag[i, j] = math.sqrt(br**2 + bz**2)

    fig, axes = plt.subplots(1, 3, figsize=(18, 6))

    # |B| contour
    c0 = axes[0].contourf(Z, R, np.log10(Bmag + 1e-10), levels=30, cmap="viridis")
    plt.colorbar(c0, ax=axes[0], label="log₁₀(|B| / T)")
    axes[0].set_xlabel("z (mm)")
    axes[0].set_ylabel("r (mm)")
    axes[0].set_title("|B| field magnitude")

    # B_z on axis
    z_axis = np.linspace(-80, 80, 500)
    bz_axis = np.array([solenoid_field(0, z, coil_params)[1] for z in z_axis])
    axes[1].plot(z_axis, bz_axis * 1e3, "b-", linewidth=2)
    axes[1].set_xlabel("z (mm)")
    axes[1].set_ylabel("B_z (mT)")
    axes[1].set_title("B_z on axis (r=0)")
    axes[1].axhline(0, color="gray", linestyle="--", alpha=0.5)
    L = coil_params["length_mm"]
    axes[1].axvspan(-L / 2, L / 2, alpha=0.1, color="red", label="coil region")
    axes[1].legend()
    axes[1].grid(True, alpha=0.3)

    # B_r off axis — should be 0 at r=0
    r_test = [0, 2, 5, 10, 20]
    for r_val in r_test:
        br_line = np.array([solenoid_field(r_val, z, coil_params)[0] for z in z_axis])
        axes[2].plot(z_axis, br_line * 1e3, label=f"r={r_val} mm")
    axes[2].set_xlabel("z (mm)")
    axes[2].set_ylabel("B_r (mT)")
    axes[2].set_title("B_r vs z at various r")
    axes[2].legend()
    axes[2].grid(True, alpha=0.3)

    plt.tight_layout()
    plt.savefig(PLOTS_DIR / "bfield_validation.png", dpi=150)
    plt.close()
    print(f"Saved: {PLOTS_DIR / 'bfield_validation.png'}")

    # 2. Force plot
    z_force = np.linspace(-60, 60, 300)
    forces_r = np.zeros_like(z_force)
    forces_z = np.zeros_like(z_force)
    for i, z in enumerate(z_force):
        fr, fz = ferromagnetic_force(0, z, 5.0, coil_params)
        forces_r[i] = fr
        forces_z[i] = fz

    fig, ax = plt.subplots(figsize=(10, 5))
    ax.plot(z_force, forces_z, "r-", linewidth=2, label="F_z (axial)")
    ax.set_xlabel("z (mm)")
    ax.set_ylabel("Force (mN)")
    ax.set_title("Axial force on marble along coil axis (r=0)")
    ax.axvspan(-L / 2, L / 2, alpha=0.1, color="blue", label="coil region")
    ax.legend()
    ax.grid(True, alpha=0.3)
    plt.tight_layout()
    plt.savefig(PLOTS_DIR / "em_force_on_axis.png", dpi=150)
    plt.close()
    print(f"Saved: {PLOTS_DIR / 'em_force_on_axis.png'}")


def main():
    params = json.loads(CONFIG_PATH.read_text())

    # Quick validation: on-axis center field
    Br_0, Bz_0 = solenoid_field(0, 0, params)
    print(f"B-field at center (r=0, z=0): B_r={Br_0:.6f} T, B_z={Bz_0:.6f} T ({Bz_0*1e3:.3f} mT)")

    # Symmetry check: B_r should be 0 on axis
    Br_check, _ = solenoid_field(0, 10, params)
    print(f"B_r at (r=0, z=10): {Br_check:.2e} T (should be ~0)")

    # Force at entry
    Fr, Fz = ferromagnetic_force(0, -20, 5.0, params)
    print(f"Force at (r=0, z=-20mm): F_r={Fr:.4f} mN, F_z={Fz:.4f} mN")

    validate_and_plot(params)


if __name__ == "__main__":
    main()

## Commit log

2026-03-17 Initial commit: magnetic coil marble coaster digital twin
    Complete simulation pipeline for a magnetic coil-launched marble roller coaster:
    - STL to OpenUSD conversion with physics, materials, and lighting
    - Parametric coil generator with custom USD attributes
    - Analytical B-field computation (Biot-Savart with elliptic integrals)
    - EM force injection with LR circuit pulse timing
    - Gravity-only and EM-assisted marble simulations
    - NVIDIA Kit app with PhysX integration and control UI
    - Physics validation suite cross-checked against textbook formulas
    - PINN training infrastructure (GPU optional)
    - Warp GPU kernels and differentiable optimization (GPU optional)
    Physics verified: B-field within 1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
    [track.stl]
2026-03-18 PINN validation suite, v4 training, Kit integration fixes
    Physics-Informed Neural Network:
    - Rewrote evaluate_pinn.py as 5-level validation suite (field accuracy,
    gradient accuracy, force accuracy, design space coverage, physics
    consistency) with structured PASS/FAIL reporting, plots, and JSON output
    - Improved training data generation: 1.02M samples (up from 414k) with
    boundary-enriched sampling at coil ends/winding radius, on-axis
    enrichment, and explicit design space grid corners
    - Enhanced training: 200k steps, physics loss weights 10x (curl/div 1.0),
    symmetry loss, gradient self-consistency loss, progressive ramp
    - Trained v4 checkpoint on RTX 5090: 3/5 validation levels now p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
    [track-starter-slope.stl]
2026-03-19 Adopt dual-baseline PINN strategy after audit-driven retraining
    Checkpoint sweep confirms L1 max vs L4 coverage is a real tradeoff,
    not a checkpoint-selection issue. No intermediate checkpoint achieves
    both v4-style L1 max (<20%) and v7-style L4 completeness (100%).
    Dual baselines:
    - pinn_designspace.pt (v7): primary production model for Kit/force/
    design exploration. Passes L2 (P99=3.7%), L3, L4 (100%). L1 max
    error (37%) concentrated in singular-boundary regions, does not
    prevent force accuracy from passing.
    - pinn_fieldaccuracy.pt (v4 recipe): conservative field baseline for
    strict pointwise accuracy. Needs retraining (original overwritten).
    Audit-driven changes:
    - Level 2 crite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
    [analytical_bfield.py]
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2026-07-02 First Kit/PhysX launch artifact: 300V run, 4.5x measured boost
    Adds a scripted autorun mode to the extension for reproducible launch
    runs (--/exts/omni.marble.coaster/autorun=true, autorunVoltage=300):
    loads the scene, configures PhysX, overrides the charge voltage,
    starts the sim, stops after the exit gates fire, writes the trajectory
    CSV, and quits. Fixes a Python scoping bug (local `import omni.kit.app`
    shadowed the module-level omni) by importing at module level.
    Committed artifact kit_launch_300V_470uF_20260702_174018.csv is the
    first trajectory generated by the real Kit/PhysX/PINN path (v8
    step-250k checkpoint, derived-B). Telemetry:
    - approach 208 mm/s (vel_in gates), coil fired at e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
    [kit_launch_300V_470uF_20260702_174018.csv]
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2026-07-03 Driver board BOM (LCSC/JLC-verified) and part-driven design calcs
    hardware/scripts/parts.py: single source of truth for the selected
    parts, all verified in-stock on LCSC 2026-07-02/03 with alternates.
    Highlights: 3x SCILICON SFT040N150C3 (TOLL 150V, 760A pulse) switch,
    5x YFW MBR60100DC Schottky (blocking/freewheel/clamp), Yezhan 0.2mOhm
    5930 shunt + INA240A1 + ADS7042 sense chain, LM3481 boost charger,
    UCC27524A gate drive, Hongfa relays. Bank revised to 5x 2200uF/63V
    snap-in positions (63V/4700uF snap-ins don't exist on LCSC); baseline
    2 cans = 4400uF, max 11000uF.
    calcs.py now consumes parts.py constants; all 12 margins PASS with the
    real parts — worst case 458A/1.1ms/19.8J at 11000uF,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
    [bom.csv]
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2026-07-03 Address external design review: boost FB + OVP redesign, BOM freeze
    Review findings accepted and fixed (each verified by machine check):
    1. Boost feedback network was wrong (confirmed: as-drawn spanned
    54-68V with PWM inverted vs the comment). Redesigned: RT/RB/RJ =
    100k/10k/9.1k with the exact transfer function documented in the
    schematic and design-calcs.md. PWM=0 (MCU-dead state) commands
    55.0V; full PWM commands 18.7V (below the 24.5V converter floor).
    New calcs.py asserts both endpoints.
    2. OVP tripped at 55.6V, not the claimed 63V (confirmed). Redesigned:
    CJ431 (+/-0.5%) + 100k/4.3k 1% -> 60.5V nominal, 59.1-62.0V across
    tolerances. Protection ladder asserted in c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
    [bom.csv, bom_rail_emit.csv, bom_rail_recv.csv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]
2026-07-03 Re-audit hygiene fixes: stale labels, COMMON variant, production gate
    All six re-audit findings addressed:
    1. Rail variant BOMs now include Variant=COMMON parts (J1 RAIL-IDC
    appears in both bom_rail_emit.csv and bom_rail_recv.csv).
    2. design-calcs.md headings derive from V_BANK_MAX instead of
    hardcoded "60V" strings.
    3. OVP reference wording unified to CJ431 +/-0.5% everywhere (the
    math already used ref_tol=0.005; text now matches).
    4. Stale "57.2V OVP floor" magic number in the boost comment replaced
    with a reference to the calcs.py protection-ladder asserts.
    5. validate.py --production mode: ORDER-REVIEW placeholder LCSC
    values fail (exit 1) at fab/assembly export; review mo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
    [bom.csv, bom_rail_emit.csv, bom_rail_recv.csv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]
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2026-07-03 Datasheet-exact footprints, placement engine, scripted PCB router WIP
    - gen_footprints.py: TOLL-8, D2PAK (cathode-tab corrected), 5930 shunt,
    9.5mm barrier, HF3FF relay land patterns; drop _DRAFT footprints
    - placement.py: 220x150 board plan, pulse zone polygons derived from
    package pad windows, shelf-packed clusters, Kelvin/manual tracks
    - gen_pcb.py: netlist->board generator with zone builder, via stitching,
    pad-in-zone assertions, straggler/GND-drop/escape pre-routes and a
    negotiated-congestion (PathFinder-lite) signal router + greedy cleanup
    - debug_route.py/debug_map.py/debug_j7.py: router diagnostics
    [boost_charger.kicad_sch, cap_bank.kicad_sch, flyback.kicad_sch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]
2026-07-03 Gate-rail PCB: DRC-clean 224x15mm rail, driver preroute/freerouting flow
    - gen_rail_pcb.py: deterministic planar wiring (F/B split lanes),
    station-x assertions to 0.01mm, EMIT/RECV checkboxes, fiducial
    - gate-rail DRC: 0 errors, 0 unconnected
    - gen_pcb.py: preroute/import-ses/repair phases, LT_POWER inner layers,
    grid-aware SES import, mounting holes with annular pads
    [gate-rail.kicad_pcb, omnimarble-driver.dsn, omnimarble-driver.kicad_pcb]
2026-07-03 Driver PCB checkpoint: placement + power/pulse copper + planes
    Board state: all 178 footprints placed in functional zones (collision-
    free), 20 zones filled (In1/In2 solid GND planes at 91%, F/B pulse
    pours at 25% leaving 75% open for signal routing), pulse-path copper +
    Kelvin + via stitching, GND/pulse/power nets carried by planes. DSN
    re-exported from the board via pcbnew's own ExportSpecctraDSN (the
    fork's hand-rolled DSN exporter was broken - only emitted 13 stub nets).
    Signal-layer autorouting still open: freerouting v2.1.0 headless
    (--gui.enabled=false --router.max_threads=8) engages multi-thread but
    chokes with target_shape-null NPEs trying to maze-route the GND/pulse
    PLANE nets (sh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
    [omnimarble-driver.dsn, omnimarble-driver.kicad_pcb]
2026-07-04 Driver PCB: zero-shorts routing via parallel PathFinder negotiation
    - gen_pcb.py: multiprocessing negotiation (24 workers, shared-memory
    usage/hist, sub-batch dispatch, ~14x wall time), best-state snapshot
    with restore-before-emit, stagnation break, width-aware swaths in all
    A* passes, verify-before-emit, contested-cell sentinel, tie/stub body
    checks, GND-drop relaxed site tests + far-ring recovery, straggler
    width ladder, geometric purge_track_shorts backstop
    - route_worker.py: pcbnew-free worker module (Windows spawn safe)
    - Board DRC: shorting_items 199 -> 0, tracks_crossing 25 -> 0,
    clearance 499 -> 56; unconnected 143 (honest residue: 52 route
    failures + GND drops + purged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
    [omnimarble-driver.dsn, omnimarble-driver.kicad_pcb]
2026-07-04 Driver PCB: repair pass + KiCad-10 via-assert fix (unconnected 143->118)
    - Fix repair/grid-build hang: PCB_VIA.GetWidth() with no layer arg fires
    a blocking wx assert in KiCad 10 (only triggered when loading an
    already-routed board with vias, so scripted mode never hit it). Read
    diameter with a layer arg, fall back to 0.6mm.
    - main_repair now runs purge_track_shorts before save, so closing
    unconnected pairs can never leave a short behind.
    - Board: shorts 0, crossings 0, clearance 58, unconnected 143->118
    (repair routed 82, purge removed 9 boundary touches). Residual
    unconnected are long cross-board signal nets for manual finishing.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
    [omnimarble-driver.kicad_pcb]
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2026-07-04 Driver PCB: fix schematic parity + correct review overclaims
    Addresses external review pushback on the "DRC-clean/fab-ready" framing.
    - Schematic parity now 0 (was 6): footprint DNP synced for C92-94; TP1/
    NT1/NT2 excluded from BOM in schematic (test point + Kelvin net-ties).
    kicad_sch.add_symbol gains in_bom kwarg so this can't regress.
    - REVIEW_HANDOFF.md rev 2: drops "DRC-clean copper" overclaim. States
    honestly this is an iteration checkpoint, not fab-ready: 59 real
    clearance errors (near-shorts to 0.010mm on FIRE_GATED/gate/BOOST_EN_N/
    ESTOP nets), 118 unconnected incl 34 safety/control/analog. Clarifies
    board is byte-identical (sha256 ed02f3b) across e64fb78/bb3ea38/ae83eb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
    [flyback.kicad_sch, omnimarble-driver.kicad_pcb, pulse_switch.kicad_sch]
2026-07-04 Driver PCB: pivot to freerouting bulk routing (118 -> 13 unconnected)
    Replace the from-scratch PathFinder router for signal routing with a
    prepared-DSN + freerouting v2.2.4 flow. Investigation showed freerouting's
    prior failures were fixable pipeline defects, not board complexity.
    Pipeline: preroute -> dsn_fixup -> freerouting -> import-ses -> DRC
    - dsn_fixup.py (new): rewrites KiCad's single net-class into per-width
    classes so real widths reach the router; locks all critical + pulse
    copper (type route -> type fix) so the router can't rip authored copper.
    - placement.py: CRITICAL_NETS / PLANE_NETS / netclass_rules() taxonomy.
    - freerouting v2.2.4 on JDK 26, headless, max_passes=30 (was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
    [omnimarble-driver.dsn]
2026-07-04 Driver PCB: finishing pass - pulse clearance + stitch-via hole spacing
    - netclass_rules: pulse/bank nets (VBANK/AUX_BANK/...) carry the 1.0mm
    bank-voltage clearance in the DSN, so the router keeps signals off the
    high-current copper. clearance 12->6, hole_clearance 4->0.
    - stitch_zone: skip stitch points within hole-to-hole of THT pad holes.
    hole_to_hole 6->0.
    - gnd_via_drops: hole-clash guard on via-in-pad.
    State: 0 shorts / 0 crossings / 0 parity / 0 hole_to_hole / 0 hole_clearance,
    6 clearance, 13 unconnected (5 congested GND + SHUNT_HI/BST_G Kelvin+boost
    + a few signal taps -> manual/critical-authoring finish).
    [omnimarble-driver.dsn]
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2026-07-04 Driver PCB: finishing pass 2 — address external review DRC items
    All reviewer-flagged DRC items now zero (0 shorts/crossings/clearance/
    copper-edge/hole/parity; only 2 cosmetic text_height + 10 unconnected remain).
    - U10 VSSOP fine-pitch: documented pad-to-pad 0.14mm rule (.kicad_dru) so the
    manufacturer land pattern's 0.15mm gap passes; tracks stay 0.2mm. clearance 6->0.
    - VBOOST edge (charged rail): 1.5mm perimeter track/via keepout + VBOOST width
    2.0->1.5mm (ample for ~0.5A charge current). copper_edge 3->0.
    - Co-located SW_DRAIN vias: dedup_vias() in finish. holes_co_located 2->0.
    - Vias tented top+bottom; via-in-pad GND still needs filled/capped (POFV) at fab
    (documented). via_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
    [omnimarble-driver.dsn]
2026-07-04 Driver PCB: keep freerouting for critical nets (author-then-lock crashes FR)
    Blanket A* authoring of the critical nets, exported as DSN (type fix) wires,
    crashes freerouting v2.2.4 in insert_forced_trace_polyline ('from_corner is
    null' on the short diagonal pad ties) - and A* itself can't cross the pulse
    pours for 13 of the edges. Reverted the preroute route_critical() call
    (function kept for possible import-time / targeted use).
    Critical nets are routed by freerouting (connected, DRC-clean) and will be
    reviewed via highlighted-net screenshots; any inadequate net gets a clean
    explicit MANUAL_TRACKS trace (which freerouting digests), not an astar pass.
    Also retained from this pass: remove_d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
    [omnimarble-driver.kicad_pcb]
2026-07-04 Driver PCB: fix BST_G boost-gate placement (37.8mm -> 3.6mm)
    Targeted critical-net fix from the routing-quality review. R6 (boost gate
    resistor) was ~19mm from Q91's gate despite its "beside Q91" comment, giving a
    37.8mm BST_G loop (ratio 1.9). Moved R6 above Q91 (clear of L2/R7) so
    pad2(BST_G) is 3.3mm from Q91.G -> BST_G now 3.6mm, ratio 1.1 (direct, F.Cu
    only, source-referenced). DRV1 also improved (1.9->1.5); BOOST_EN_N/VSET_PWM
    now connected + direct.
    Board: 0 shorts/clearance/parity/courtyard, 11 unconnected (freerouting
    congestion in dense areas), 2 text_height, 1 via_dangling. NOTE: repair-mode
    A* is counterproductive on a freerouted board (coarse grid vs FR's dense copper
    -> shorts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
    [omnimarble-driver.dsn, omnimarble-driver.kicad_pcb]
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2026-07-04 netclass_rules: split bank-voltage clearance from width groups (DeepPCB fix)
    DeepPCB flagged VBOOST/BST_CS_HI pins unroutable: my width-grouped netclasses
    gave the whole 0.7mm group VBANK's 1.0mm bank-voltage clearance. Now classes
    split by (width, high-voltage), so only the true bank nets (VBANK/pulse/
    AUX_BANK) carry 1.0mm; VBOOST/BST_CS_HI drop to 0.3mm and route. The pour's own
    1.0mm isolation is a zone property, so the high-voltage copper keeps its
    creepage -- only the thin sense taps relax. Also: GND excluded from the hv set
    (it's 0V) and given its own 0.3mm class (DeepPCB rec #2); ISNS_P/N share the
    w0p3 class. Mirrors DeepPCB's accepted config changes in our source so they
    survive DS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
    [omnimarble-driver-for-deeppcb.dsn, omnimarble-driver.dsn, omnimarble-driver.kicad_pcb]
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2026-07-04 Driver PCB: pour GND last (fix fine-pitch IC boxing for DeepPCB re-route)
    DeepPCB flagged U10/U11/U12/U4/U1 pins physically unroutable: the full-board
    F/B GND pour was poured BEFORE routing and boxed in the fine-pitch signal pads.
    Fixed to the correct order -- route first, flood GND last:
    - build_zones no longer pours the outer F/B GND flood (kept only inner In1/In2
    GND planes + pulse GND strips). The boxing-free DSN lets the router escape the
    fine-pitch pads.
    - add_fb_gnd_pours() adds the F/B GND flood in import-clean AFTER the SES is
    imported, so it pours around the finished traces (thermal-connecting GND pads)
    instead of blocking them. Inner planes still carry the return.
    - (rule-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
    [omnimarble-driver-for-deeppcb.dsn, omnimarble-driver.dsn]
2026-07-04 Driver PCB: skip GND via-in-pad for DeepPCB DSN (unblocks U10 fine-pitch pads)
    DeepPCB still flagged U10-1/5/7/8 unroutable even without the boxing: build_
    preroute's gnd_via_drops was dropping 0.45mm GND vias into U10's 0.35mm GND
    pads (a via bigger than the pad), physically blocking those pins and the
    adjacent 3V3 pins. gnd_via_drops is unneeded for DeepPCB (it connects GND to
    the inner planes itself) and harmful, so main_preroute now builds with
    gnd_drops=False. Also widened COIL_HI/SW_DRAIN/SHUNT_HI to 0.5mm per DeepPCB's
    config note (still fit all pads). Re-upload the DSN for a route that can finally
    escape U10.
    [omnimarble-driver-for-deeppcb.dsn, omnimarble-driver.dsn]
2026-07-04 Driver PCB: minimal DeepPCB DSN - stop pre-solving what the router handles
    Root cause of the churn: we carried freerouting-era pre-processing into the
    DeepPCB flow, and it fought the router. Reset to a minimal DSN and let DeepPCB
    route everything:
    - reverted COIL_HI/SW_DRAIN/SHUNT_HI 1.0mm-clearance regression (it boxed the
    gate/snubber/Kelvin nets that must sit at the FETs); pulse pours back to the
    0.2mm default, only VBANK keeps the 1.0mm bank-voltage creepage.
    - gnd_via_drops stays off for the DSN (DeepPCB connects GND to the inner
    planes; our 0.45mm via-in-pad blocked U10's 0.35mm fine-pitch pads).
    - via-in-pad sizing now fits the pad (0.3mm floor) for any future post-route
    GND c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
    [omnimarble-driver-for-deeppcb.dsn, omnimarble-driver.dsn]
2026-07-04 Driver PCB: author U10 fine-pitch escape (dogbone fan-out) to close last 4
    DeepPCB (and freerouting) both fail to fan U10's four corner power/GND pins out
    past its SPI signals -- a genuine VSSOP-8 0.5mm-pitch constraint, not our
    interference. So we author it, like the Kelvin ties (author_u10_escape):
    - each blocked pin (1,7=3V3; 5,8=GND) escapes on a 0.2mm dogbone stub past the
    pad row, staggered to a full 0.45mm via in the open space beyond the package
    (0.3mm tracks/via-in-pad won't fit the 0.5mm pitch -- proven by DRC).
    - GND vias tie straight to the inner GND plane; the two 3V3 vias are open-space
    anchors the router finishes to the net (C28 sits just right of pin7).
    - 3V3 added to C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
    [omnimarble-driver-for-deeppcb.dsn, omnimarble-driver.dsn]
2026-07-05 Driver PCB: rev-108 import (U10 escape works!) + fix SHUNT_HI islanding + annular
    rev-108 route: U10 fully connected (all 8 pins) -- the authored dogbone escape
    survived the round-trip intact. Down to 2 unconnected + fixable issues:
    - SHUNT_HI: the autorouter fragmented the F.Cu pour and islanded Q10/Q11 FET
    sources from the shunt. Fix: one via ON each source pad (clear of the 5mm
    stitch grid) ties it straight to the SOLID B.Cu SHUNT_HI pour, so a
    fragmented F.Cu pour can never island a source again.
    - U10 escape via annular was 0.075mm (drill 0.3 on 0.45 via); drill -> 0.25
    gives the 0.10mm minimum.
    - ISNS_P/N: the accepted diff-pair coupled them at 20um edge gap -- unmanufac-
    tur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
    [omnimarble-driver-for-deeppcb.dsn, omnimarble-driver.dsn]
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2026-07-05 Driver PCB: author SHUNT_HI B.Cu bus + dedicated ISNS diff-pair class (fresh route prep)
    Prep for one clean full re-route with every learned fix baked in:
    - author_shunt_hi_bus(): explicit locked B.Cu bus tying all 3 pulse-FET sources
    (Q10/Q11/Q12) + shunt RS1, 2 vias per multi-pad source. The SHUNT_HI current
    path no longer depends on the F.Cu pour (which the router fragments); B.Cu
    keeps F.Cu clear for gate routing. Fixes the recurring Q10/Q11 islanding.
    - diff_ISNS net class (ISNS_P/ISNS_N, 0.3mm/0.2mm gap): prefetches the diff pair
    DeepPCB always asks about, pre-set to our 0.2mm clearance so its coupling
    can't come back at the unmanufacturable 0.02mm, and passes DRC with no
    e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
    [omnimarble-driver-for-deeppcb.dsn, omnimarble-driver.dsn, omnimarble-driver.kicad_pcb]
2026-07-05 Driver PCB: drop diff_ISNS class - route ISNS as normal nets, not a diff pair
    DeepPCB's diff-pair router ignores the class clearance and couples ISNS_P/N at
    ~0.02mm (unmanufacturable) whenever the pair is enabled -- seen at rev-108,
    rev-43, both times the whole 44mm run. As plain matched-width nets at 0.2mm
    clearance they route cleanly (rev-134 proved it: 0 clearance). The dedicated
    diff-pair class only invited the tight coupling, so ISNS_P/N go back into the
    normal 0.3mm/0.2mm w0p3 group with GND.
    [omnimarble-driver-for-deeppcb.dsn, omnimarble-driver.dsn]
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2026-07-05 Driver PCB: resolve review blockers (2oz trace width, R24 BOM, validators)
    External review caught real fab-readiness issues; all resolved:
    - BLOCKER 2oz trace width: ISNS Kelvin pair was 0.1mm (a 1oz spec; JLC 2oz min
    trace/space is 0.15mm). Widened to 0.15mm -> ~0.17mm pair spacing (both >=
    0.15mm 2oz min). Scoped `isns_kelvin_pair` rule in .kicad_dru blesses the
    sub-0.2mm pair spacing (A.NetName match); clearance to all other nets stays
    0.2mm. min_track_width -> 0.15.
    - MAJOR width source-of-truth: NET_WIDTHS["ISNS_P/N"]=0.15 is now the single
    value; local_finish narrows to it, validate_widths checks it -> PASS.
    - BLOCKER R24 6.8k-2W BOM placeholder: no verified JLC C-number and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
    [boost_charger.kicad_sch]
2026-07-05 Driver PCB: resolve R24 to a real JLC-placed part (6.8k 1W 2512, C26073)
    The "6.8k 2W" spec was inconsistent -- a 2512 is a ~1W package, and LCSC stock
    confirms it: every 6.8k 2512 that's in stock is 1W; the 1.5W and 2W variants
    are all 0-stock. Actual dissipation is 55^2/6800 = 0.44W, so 1W carries it with
    2.2x margin. R24 -> value "6.8k", LCSC C26073 (UNI-ROYAL 25121WJ0682T4E, 6.8k
    2512 1W 5%, stock 3660) -- same UNI-ROYAL family as the board's other Rs.
    No longer hand-install: validate.py --production PASSES with R24 as a placed
    part (no NOTE). Every part on the board is now JLC-placeable. BOARD_OVERVIEW
    updated. All validators + DRC still green.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
    [boost_charger.kicad_sch]
2026-07-05 docs/BOM: clear stale R24 metadata (reviewer follow-up)
    Reviewer flagged stale R24 references outliving the C26073 resolution:
    - parts.py r_bleed: was 6.8k 2W / ORDER-REVIEW / Ever-Ohms -> now UNI-ROYAL
    25121WJ0682T4E / C26073 / 6.8k 2512 1W, with in-stock alternates listed.
    - bom.csv: regenerated from parts.py (r_bleed now C26073; 0 ORDER-REVIEW).
    - BOARD_OVERVIEW.md: the validation line no longer claims R24 is a
    hand-install NOTE (it's a placed part).
    - DSN part-name annotations 6.8k-2W -> 6.8k; removed a stray _t.kicad_pcb
    test artifact.
    gen_bom.py now emits a clean order-review BOM with no placeholders.
    [bom.csv, omnimarble-driver-for-deeppcb.dsn, omnimarble-driver.dsn]
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2026-07-06 Driver PCB: resolve both safety blockers + should-fixes, re-route, DRC-clean
    Two datasheet-level blockers (invisible to netlist checks) + the should-fixes
    from two review rounds, then a full DeepPCB re-route on the corrected netlist.
    Blockers:
    - U5 shunt ref: CJ431/C3113 (pinout 1=REF,2=K,3=A) did NOT match the TL431DBZ
    footprint -> OVP dead. Now TL431BIDBZR/C41283 (+/-0.5%, 1=K,2=REF,3=A). Kept
    +/-0.5% grade (the 1% A-grade would blow the 62.0V OVP ceiling).
    - Relay HF3FF footprint had NO/NC transposed (datasheet bottom-view copied
    without mirroring) -> dump/charge logic inverted. Swapped pads 12<->14 +
    corrected silk. VERIFY WITH OHMMETER at bring-up (COM-NC @rest) -- parity is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
    [boost_charger.kicad_sch, cap_bank.kicad_sch, flyback.kicad_sch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]
2026-07-06 Driver PCB: regenerate fab package + renders for the re-routed board
    Gerbers/BOM/CPL/DRC regenerated from the corrected DRC-clean board (blocker
    fixes + DeepPCB re-route). ORDER_NOTES gains a bring-up checklist for the
    physical checks parity/DRC can't see: ohmmeter each relay COM-NC de-energized
    (the pad-swap verification), verify OVP trip before first charge, fan-cool +
    watch U2 temp (DPAK deferred), stage first power at the 25V floor.
    [bom_jlc.csv]
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2026-07-06 BOM: regenerate engineering bom.csv to match corrected parts (reviewer P2)
    CJ431->TL431BIDBZR/C41283, SMBJ33A->SMBJ26CA/C113996, 50mR->0.15ohm/C2903485.
    Was stale vs the fab BOM.
    [bom.csv]
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
